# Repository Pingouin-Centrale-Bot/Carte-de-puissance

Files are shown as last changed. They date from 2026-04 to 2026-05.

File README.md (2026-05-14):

# Carte de puissance pour le robot

## Cahier des charges
### Général
 - Connecter une batterie jusqu'à 6s avec un connecteur XT60
 - Génerer une tension 5v
 - Avoir un connecteur pour brancher un convertisseur de tension externe (qu'on appelera V')
 - Alimenter 3 autres cartes, en 3 tensions différentes (Vbatt, 5v, et V')
 - Avoir une sortie dédié à l'alimentation du Pi (sortie en Vbatt)
 - Avoir un bouton (ou entrée bouton) pour l'allumage du système (permet au système de s'éteindre complétement en cas de batterie faible)

### Sécurité du robot
 - Brancher le Bouton d'Arrêt d'Urgence (BAU)
 - Être capable de couper l'alimentation Vbatt et 5v allant vers les cartes annexes
 - Signaler l'état du BAU au Pi (à ROS)

### Protection de la batterie
 - Être capable de couper l'alimentation du Pi
 - Connaitre l'état d'alimentation du Pi (est-il allumé ?)
 - Être capable de couper l'alimentation générale
 - Diode de protection
 - Fusible

### Affichage/feedback
 - Afficher l'état de charge de la batterie (pourcentage sur afficheur 7 segment)
 - Avertissement sonore lorsque la batterie est à plat
 - LED RGB indiquant l'état du système intégré au bouton de mise en marche

### Possibilitées
 - Mesurer le courant sortant de la batterie

## Configuration du pi
Dans `/boot/firmware/config.txt` sur ubuntu :
```
#dtparam=i2c_arm=on
[all]
# So the pi shutdowns when gpio4 is pulled low
dtoverlay=gpio-shutdown,gpio_pin=3,active_low=1,gpio_pull=up
# So the pi 
dtoverlay=gpio-poweroff,gpiopin=4             
```

## Problèmes rencontrés
- [] Il faut mettre une résistance en parallèle des diodes pour le contrôle des mosfets.

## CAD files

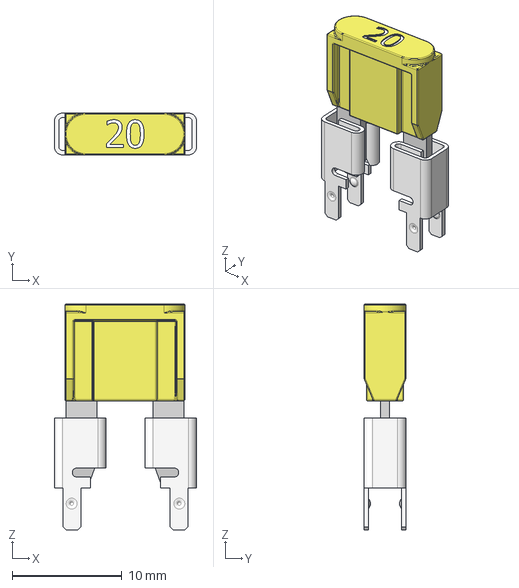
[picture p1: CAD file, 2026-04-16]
Components/3557-2_fuseholder/3557_simple.step
12.9 x 3.80 x 20.6 mm
Fusibile Lama MINI Type 2 x 3
Keystone PCB Blade Fuse Clip_001 x 2

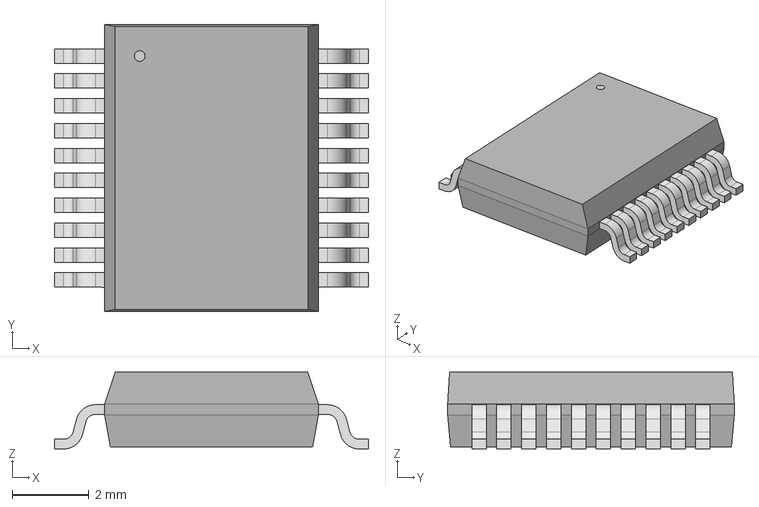
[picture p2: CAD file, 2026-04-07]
Components/ATTiny1626/SSOP20_SS_MCH.step
8.20 x 7.49 x 2.01 mm

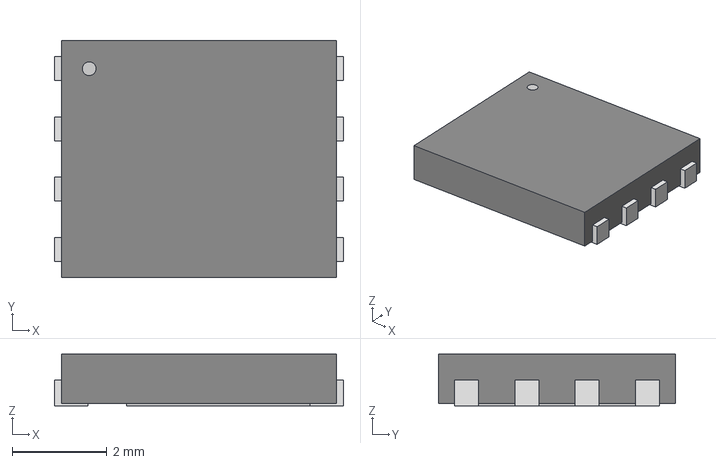
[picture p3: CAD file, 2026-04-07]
Components/GSFP6901/PPAK5X6-8L_GAS.step
6.10 x 5.00 x 1.09 mm

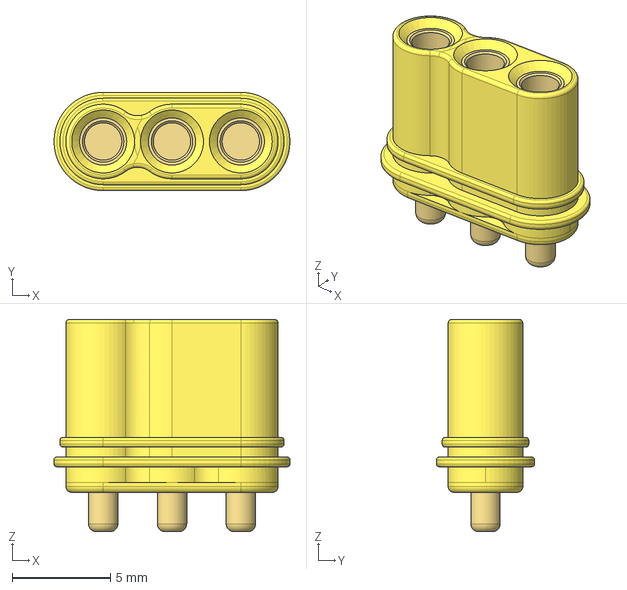
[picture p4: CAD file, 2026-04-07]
Components/MR30PB/Amass_MR30PB-FB.step
12.0 x 5.00 x 10.8 mm

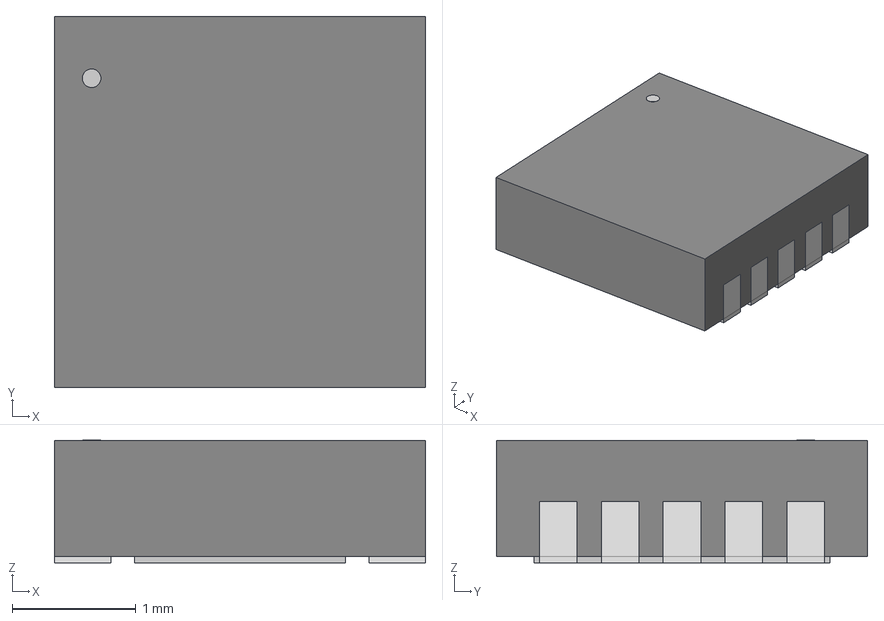
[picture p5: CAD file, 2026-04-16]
Components/PAC1811/VDFN10_9QX_MCH.step
3.00 x 3.00 x 0.993 mm

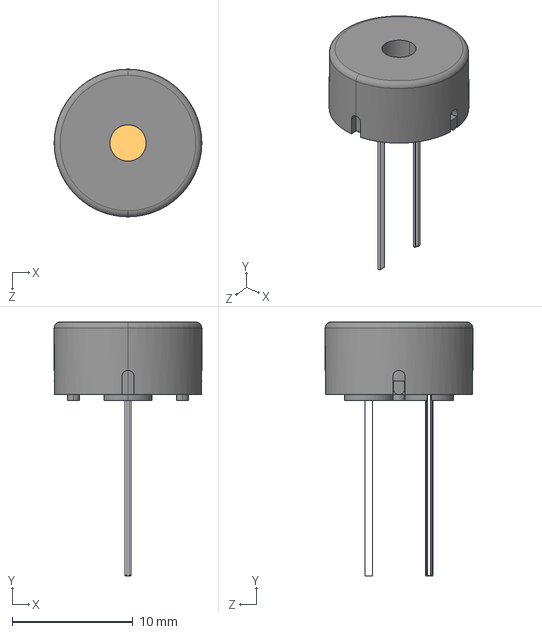
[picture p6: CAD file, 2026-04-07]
Components/PS1240P02BT/PS1240P02BT.step
12.2 x 21.0 x 12.2 mm

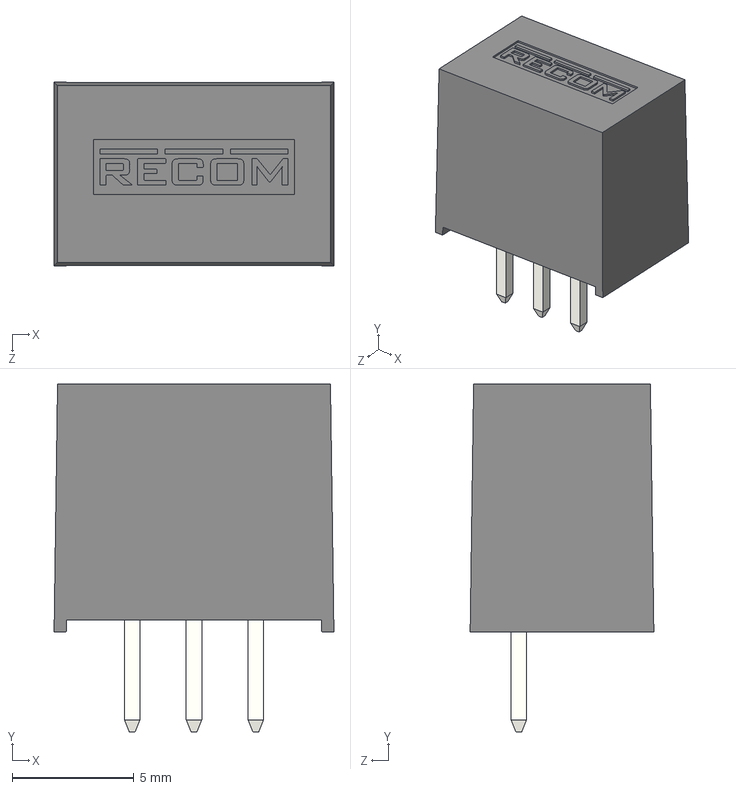
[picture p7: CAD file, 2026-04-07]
Components/R-78K-0.5/R-78K3.3-0.5.step
11.5 x 14.3 x 7.55 mm

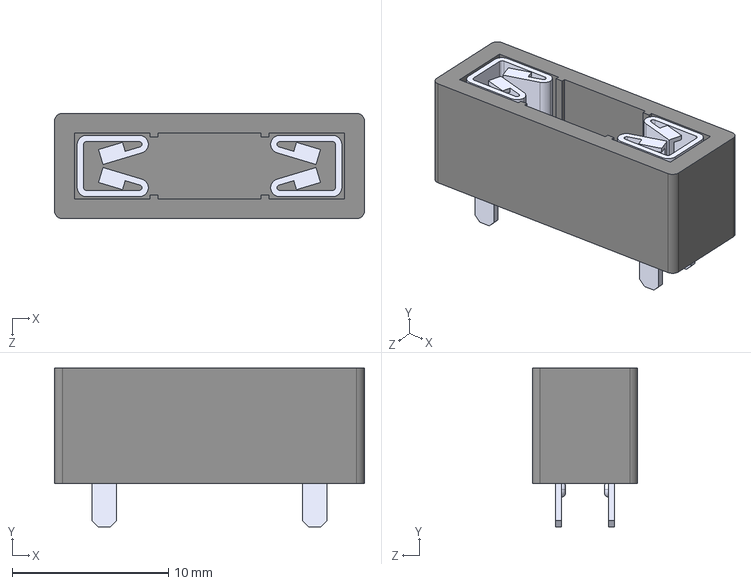
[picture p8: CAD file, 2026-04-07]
Components/3557-2_fuseholder/3557-2.step
19.8 x 10.2 x 6.73 mm

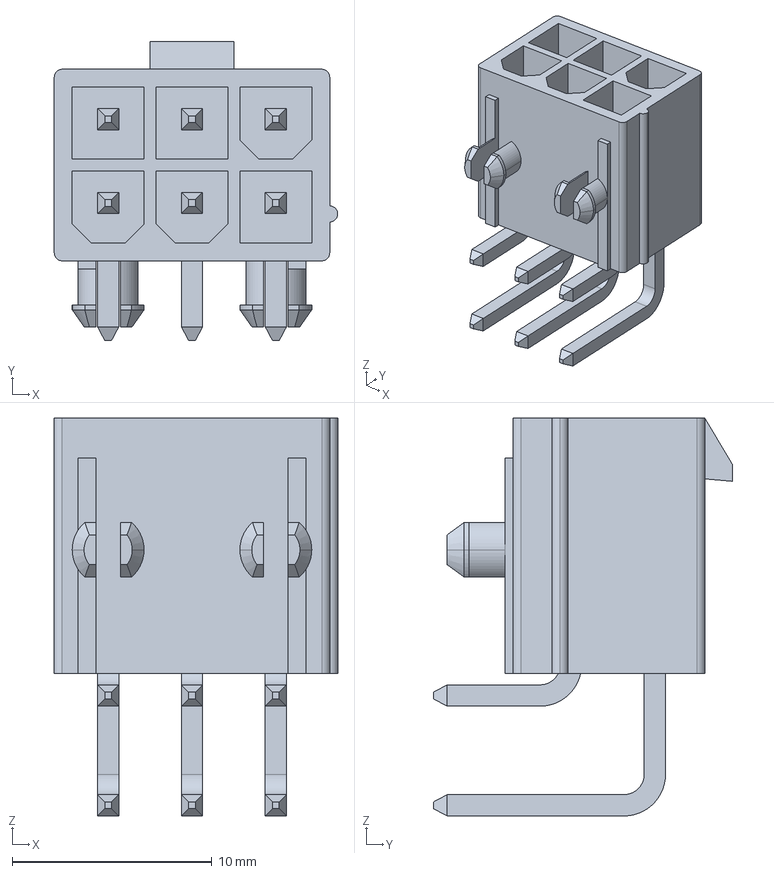
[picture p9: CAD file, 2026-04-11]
Components/Molex/0026013143.stp
14.2 x 15.0 x 19.9 mm

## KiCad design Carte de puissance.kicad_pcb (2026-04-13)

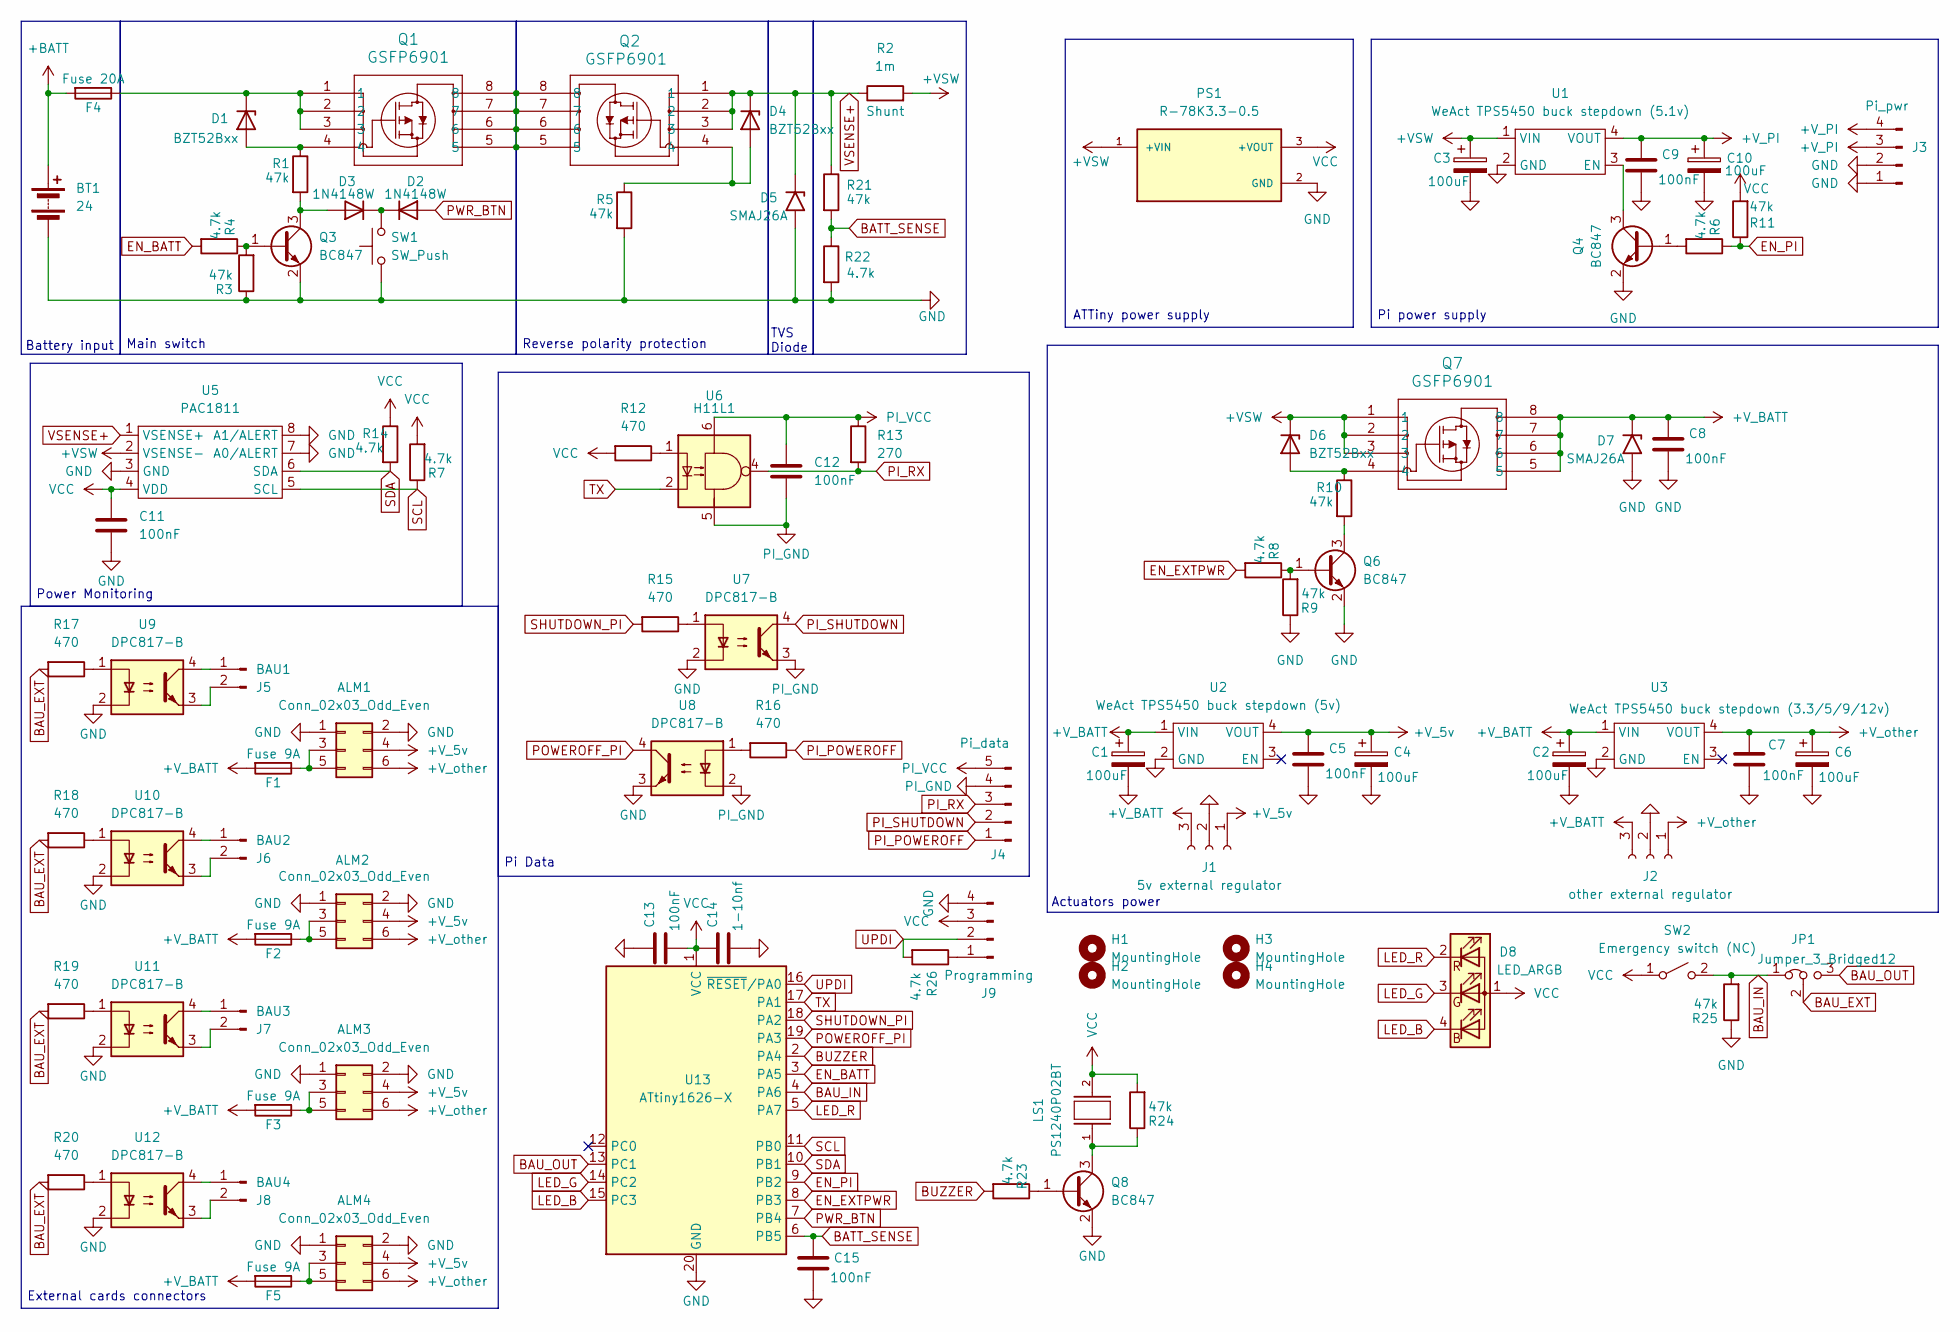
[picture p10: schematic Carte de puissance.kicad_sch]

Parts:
ALM1, ALM2, ALM3, ALM4: Conn_02x03_Odd_Even; Molex_Mini-Fit_Jr_5569-06A2_2x03_P4.20mm_Horizontal
BT1: 24; AMASS_XT60-M_1x02_P7.20mm_Vertical
C1, C2, C3, C4, C6, C10: 100uF; CP_Radial_D6.3mm_P2.50mm
C5, C7, C8, C9, C11, C12, C13, C15: 100nF; C_0805_2012Metric
C14: 1-10nf; C_0805_2012Metric
D1, D4, D6: BZT52Bxx; D_SOD-123F
D2, D3: 1N4148W; D_SOD-123
D5, D7: SMAJ26A; D_SMA
D8: LED_ARGB; JST_XH_B4B-XH-A_1x04_P2.50mm_Vertical
F1, F2, F3, F5: Fuse 9A; FUSE_3557_simple
F4: Fuse 20A; FUSE_3557_simple
H1, H2, H3, H4: MountingHole; MountingHole_3.2mm_M3
J1: 5v external regulator; MR30PB
J2: other external regulator; MR30PB
J3: Pi_pwr; JST_XH_B4B-XH-A_1x04_P2.50mm_Vertical
J4: Pi_data; JST_XH_B5B-XH-A_1x05_P2.50mm_Vertical
J5: BAU1; JST_XH_B2B-XH-A_1x02_P2.50mm_Vertical
J6: BAU2; JST_XH_B2B-XH-A_1x02_P2.50mm_Vertical
J7: BAU3; JST_XH_B2B-XH-A_1x02_P2.50mm_Vertical
J8: BAU4; JST_XH_B2B-XH-A_1x02_P2.50mm_Vertical
J9: Programming; PinHeader_1x04_P2.54mm_Vertical
JP1: Jumper_3_Bridged12; PinHeader_1x03_P2.54mm_Vertical
LS1: PS1240P02BT; XDCR_PS1240P02BT
PS1: R-78K3.3-0.5; CONV_R-78K3.3-0.5; PARTREV 0/2023
Q1, Q2, Q7: GSFP6901; PPAK5X6-8L_GAS
Q3, Q4, Q6, Q8: BC847; SOT-23
R1, R3, R5, R9, R10, R11, R21, R24, R25: 47k; R_0805_2012Metric
R2: 1m; R_2512_6332Metric
R4, R6, R7, R8, R14, R22, R23, R26: 4.7k; R_0805_2012Metric
R12, R15, R16, R17, R18, R19, R20: 470; R_0805_2012Metric
R13: 270; R_0805_2012Metric
SW1: SW_Push; JST_XH_B2B-XH-A_1x02_P2.50mm_Vertical
SW2: Emergency switch (NC); JST_XH_B2B-XH-A_1x02_P2.50mm_Vertical
U1: WeAct TPS5450 buck stepdown (5.1v); WeAct TPS5450 Buck Stepdown
U2: WeAct TPS5450 buck stepdown (5v); WeAct TPS5450 Buck Stepdown
U3: WeAct TPS5450 buck stepdown (3.3/5/9/12v); WeAct TPS5450 Buck Stepdown
U5: PAC1811
U6: H11L1; SMDIP-6_W9.53mm
U7, U8, U9, U10, U11, U12: DPC817-B; SMDIP-4_W11.48mm
U13: ATtiny1626-X; SSOP-20_5.3x7.2mm_P0.65mm

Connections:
+BATT: BT1.1 (+), F4.2
+VSW: C3.1, D6.1 (K), PS1.1 (+VIN), Q7.1, Q7.2, Q7.3, R2.2, U1.1 (VIN), U5.2 (VSENSE-)
+V_5v: ALM1.4, ALM2.4, ALM3.4, ALM4.4, C4.1, C5.1, J1.1, U2.4 (VOUT)
+V_BATT: C1.1, C2.1, C8.1, D7.1 (A1), F1.2, F2.2, F3.2, F5.2, J1.3, J2.3, Q7.5, Q7.6, Q7.7, Q7.8, U2.1 (VIN), U3.1 (VIN)
+V_PI: C9.1, C10.1, J3.3, J3.4, U1.4 (VOUT)
+V_other: ALM1.6, ALM2.6, ALM3.6, ALM4.6, C6.1, C7.1, J2.1, U3.4 (VOUT)
BATT_SENSE: C15.1, R21.2, R22.1, U13.6 (PB5)
BAU_EXT: JP1.2 (C), R17.2, R18.2, R19.2, R20.2
BAU_IN: JP1.1 (A), R25.2, SW2.2 (B), U13.4 (PA6)
BAU_OUT: JP1.3 (B), U13.13 (PC1)
BUZZER: R23.2, U13.2 (PA4)
EN_BATT: R4.2, U13.3 (PA5)
EN_EXTPWR: R8.2, U13.8 (PB3)
EN_PI: R6.1, R11.1, U13.9 (PB2)
GND: ALM1.1, ALM1.2, ALM2.1, ALM2.2, ALM3.1, ALM3.2, ALM4.1, ALM4.2, BT1.2 (-), C1.2, C2.2, C3.2, C4.2, C5.2, C6.2, C7.2, C8.2, C9.2, C10.2, C11.2, C13.1, C14.2, C15.2, D5.2 (A2), D7.2 (A2), J1.2, J2.2, J3.1, J3.2, J9.4, PS1.2 (GND), Q3.2 (E), Q4.2 (E), Q6.2 (E), Q8.2 (E), R3.1, R5.2, R9.1, R22.2, R25.1, SW1.1, U1.2 (GND), U2.2 (GND), U3.2 (GND), U5.3 (GND), U5.7 (A0/ALERT), U5.8 (A1/ALERT), U7.2, U8.3, U9.2, U10.2, U11.2, U12.2, U13.20 (GND)
LED_B: D8.4 (BK), U13.15 (PC3)
LED_G: D8.3 (GK), U13.14 (PC2)
LED_R: D8.2 (RK), U13.5 (PA7)
unnamed: ALM1.3, ALM1.5, F1.1
unnamed: ALM2.3, ALM2.5, F2.1
unnamed: ALM3.3, ALM3.5, F3.1
unnamed: ALM4.3, ALM4.5, F5.1
unnamed: D1.2 (A), Q1.4, R1.1
unnamed: D1.1 (K), F4.1, Q1.1, Q1.2, Q1.3
unnamed: D2.1 (K), D3.1 (K), SW1.2
unnamed: D3.2 (A), Q3.3 (C), R1.2
unnamed: D4.2 (A), Q2.4, R5.1
unnamed: D6.2 (A), Q7.4, R10.1
unnamed: J5.1, U9.4
unnamed: J5.2, U9.3
unnamed: J6.1, U10.4
unnamed: J6.2, U10.3
unnamed: J7.1, U11.4
unnamed: J7.2, U11.3
unnamed: J8.1, U12.4
unnamed: J8.2, U12.3
unnamed: J9.1, R26.1
unnamed: Q1.5, Q1.6, Q1.7, Q1.8, Q2.5, Q2.6, Q2.7, Q2.8
unnamed: Q3.1 (B), R3.2, R4.1
unnamed: Q4.1 (B), R6.2
unnamed: Q4.3 (C), U1.3 (EN)
unnamed: Q6.1 (B), R8.1, R9.2
unnamed: Q6.3 (C), R10.2
unnamed: Q8.1 (B), R23.1
unnamed: LS1.1, Q8.3 (C), R24.1
unnamed: R12.1, U6.1
unnamed: R15.1, U7.1
unnamed: R16.2, U8.1
unnamed: R17.1, U9.1
unnamed: R18.1, U10.1
unnamed: R19.1, U11.1
unnamed: R20.1, U12.1
PI_GND: C12.2, J4.4, U6.5, U7.3, U8.2
PI_POWEROFF: J4.1, R16.1
PI_RX: J4.3, R13.2, U6.4
PI_SHUTDOWN: J4.2, U7.4
PI_VCC: C12.1, J4.5, R13.1, U6.6
POWEROFF_PI: U8.4, U13.19 (PA3)
PWR_BTN: D2.2 (A), U13.7 (PB4)
SCL: R7.1, U5.5 (SCL), U13.11 (PB0)
SDA: R14.2, U5.6 (SDA), U13.10 (PB1)
SHUTDOWN_PI: R15.2, U13.18 (PA2)
TX: U6.2, U13.17 (PA1)
UPDI: J9.2, R26.2, U13.16 (~RESET/PA0)
VCC: C11.1, C13.2, C14.1, D8.1 (A), J9.3, LS1.2, PS1.3 (+VOUT), R7.2, R11.2, R12.2, R14.1, R24.2, SW2.1 (A), U5.4 (VDD), U13.1 (VCC)
VSENSE+: D4.1 (K), D5.1 (A1), Q2.1, Q2.2, Q2.3, R2.1, R21.1, U5.1 (VSENSE+)

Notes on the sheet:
Actuators power
ATTiny power supply
Pi Data
Pi power supply
External cards connectors
Power Monitoring
Main switch
TVS Diode
Battery input
Reverse polarity protection

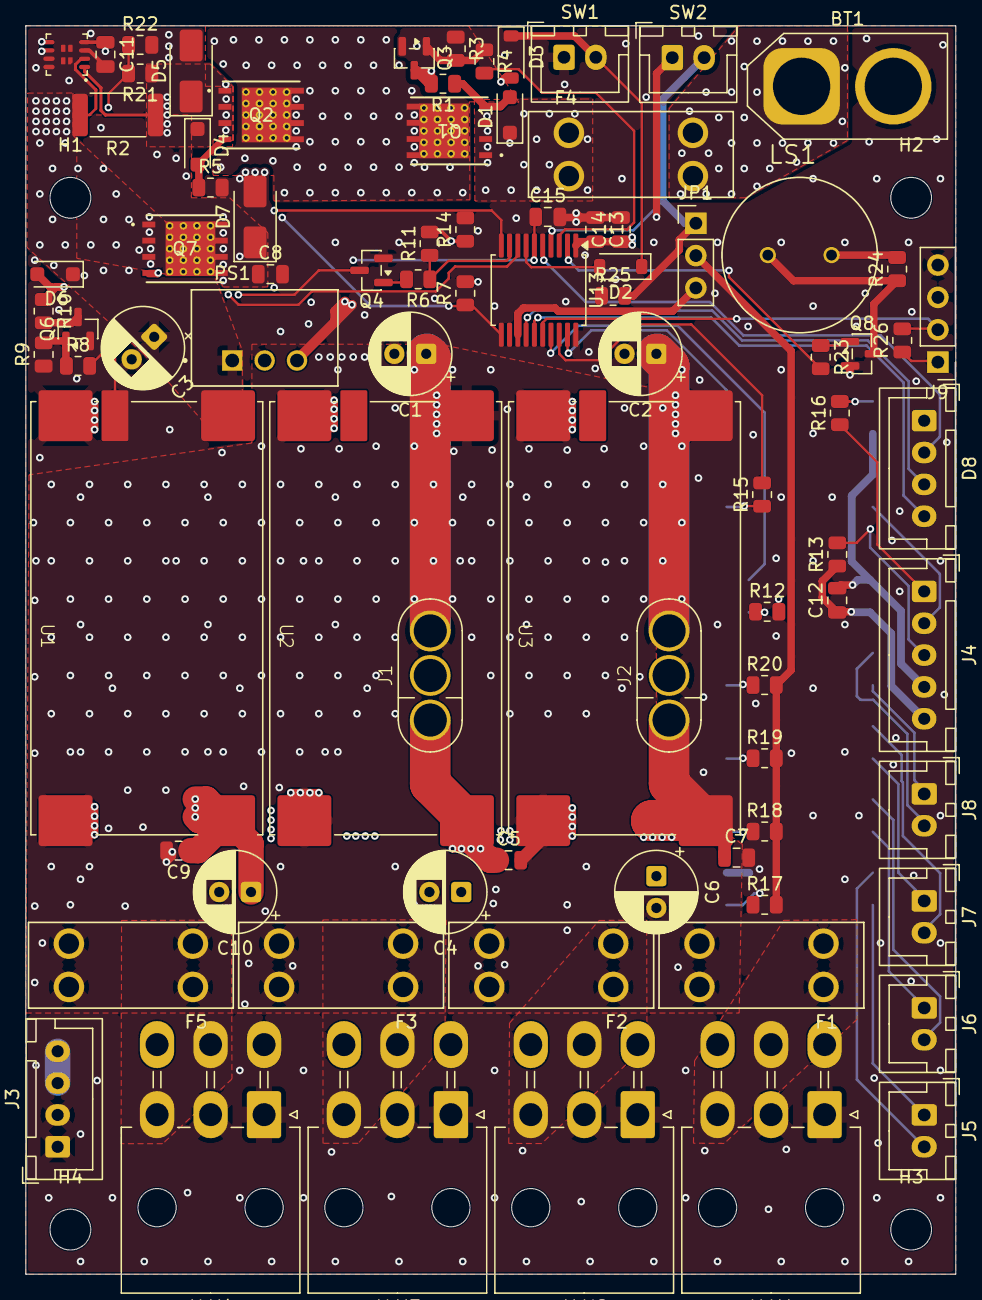
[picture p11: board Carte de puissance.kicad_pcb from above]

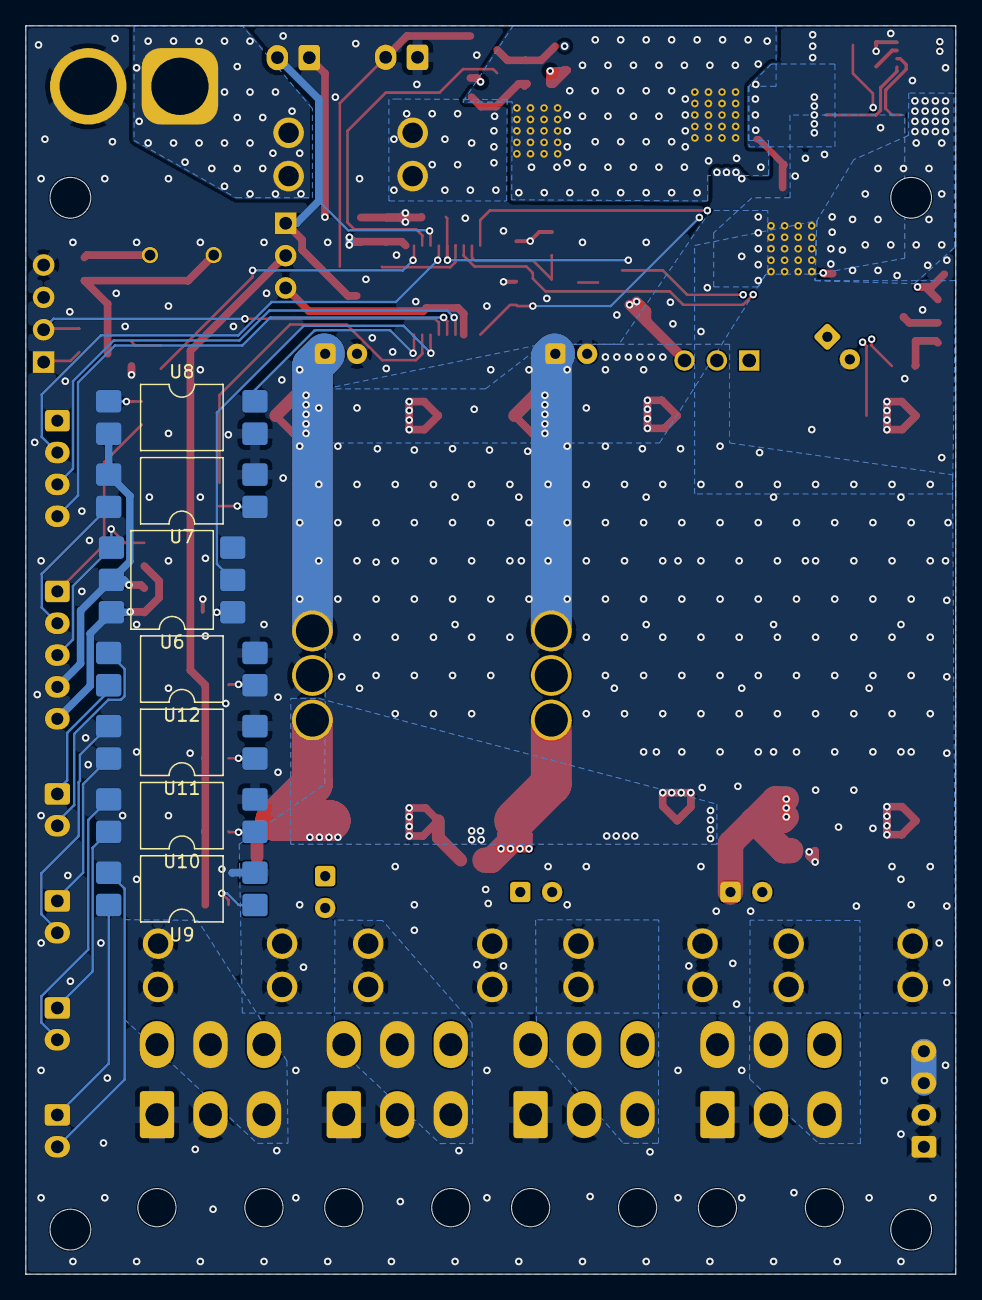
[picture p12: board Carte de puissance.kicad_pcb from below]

Board: 4 copper layers, 73.0 x 98.0 mm, 96 parts (7 on the bottom side), 66 nets.

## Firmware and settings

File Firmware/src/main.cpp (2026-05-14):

#include <Arduino.h>
#include "config.hpp"

enum Msg
{
  CRITICAL_LOW_BATT_MSG,
  CRITICAL_HIGH_BATT_MSG,
  PI_NOT_OFF_MSG,
  NORMAL_OFF_MSG,
  POWERING_UP_MSG
};

enum BattState
{
  START_BATT_STATE,
  HIGH_BATT_STATE,
  NORMAL_BATT_STATE,
  MEDIUM_BATT_STATE,
  LOW_BATT_STATE,
  VERY_LOW_BATT_STATE,
  POWERING_OFF_ENTER,
  POWERING_OFF_WAITING_FOR_PI
};
volatile BattState batt_state = START_BATT_STATE;
volatile unsigned long powering_off_enter_time = 0;

enum BAUState
{
  IDLE_BAU,
  PRESSED_TIMEOUT_BEFORE_POWERCUT,
  POWERCUT
};

volatile BAUState BAU_state = IDLE_BAU;
volatile bool BAU_state_changed;

void handle_bau()
{
  if (BAU_state == IDLE_BAU && !(batt_state >= POWERING_OFF_ENTER))
  {
    BAU_state = PRESSED_TIMEOUT_BEFORE_POWERCUT;
    digitalWriteFast(BAU_OUT, LOW);
    BAU_state_changed = true;
    tone(BUZZER, LOW_NOTE, 2000);
  }
}

void handle_power_btn()
{
  if (millis() >= 1500 && batt_state < POWERING_OFF_ENTER) // To prevent issues if pressed too soon with debouncing
  {
    powering_off_enter_time = millis();
  }
}

uint16_t readVoltageMV()
{
  return analogRead(BATT_SENSE) * (2.5 / 4095) * ((47 + 4.7) / 4.7) * BATT_CORRECT * 1000;
}

inline void setRGB(Color c)
{
  digitalWriteFast(LED_R, ((c >> 2) & 0x01) == 0);
  digitalWriteFast(LED_G, ((c >> 1) & 0x01) == 0);
  digitalWriteFast(LED_B, ((c >> 0) & 0x01) == 0);
}

inline void playCode(Color c, unsigned int tone_f, bool end_delay = true)
{
  tone(BUZZER, tone_f);
  setRGB(c);
  delay(100);
  if (!end_delay)
  {
    delay(100);
  }
  noTone(BUZZER);
  setRGB(Black);
  if (end_delay)
  {
    delay(100);
  }
}

void playMsg(Msg error)
{
  switch (error)
  {
  case CRITICAL_HIGH_BATT_MSG:
    playCode(HIGH_COLOR, HIGH_NOTE);
    playCode(HIGH_COLOR, HIGH_NOTE);
    playCode(HIGH_COLOR, HIGH_NOTE);
    Serial1.println("Critical high batt");
    break;
  case CRITICAL_LOW_BATT_MSG:
    playCode(LOW_COLOR, LOW_NOTE);
    playCode(LOW_COLOR, LOW_NOTE);
    playCode(LOW_COLOR, LOW_NOTE);
    Serial1.println("Critical low batt");
    break;
  case PI_NOT_OFF_MSG:
    playCode(HIGH_COLOR, HIGH_NOTE);
    playCode(MEDIUM_COLOR, MEDIUM_NOTE);
    playCode(HIGH_COLOR, HIGH_NOTE);
    playCode(MEDIUM_COLOR, MEDIUM_NOTE);
    // Followed by normal power off.
  case NORMAL_OFF_MSG:
    playCode(HIGH_COLOR, HIGH_NOTE, false);
    playCode(MEDIUM_COLOR, MEDIUM_NOTE, false);
    playCode(LOW_COLOR, LOW_NOTE, false);
    break;
  case POWERING_UP_MSG:
    playCode(LOW_COLOR, LOW_NOTE, false);
    playCode(MEDIUM_COLOR, MEDIUM_NOTE, false);
    playCode(HIGH_COLOR, HIGH_NOTE, false);
    break;
  }
}

void unplugBattery()
{
  digitalWriteFast(EN_BATT, LOW);
  delay(2000);
  tone(BUZZER, 2489); // Should be off by now. The tone indicates user should disconnect power ASAP.
  while (true)
    ;
}

bool updateBattState() // Will unplug if battery critical
{
  uint16_t batt_voltage = readVoltageMV();
  Serial1.printf("Voltage: %d;\n", batt_voltage);
  if (batt_voltage >= CRITICAL_HIGH_BATT)
  {
    playMsg(CRITICAL_HIGH_BATT_MSG);
    unplugBattery(); // Never returns
  }
  else if (batt_voltage <= CRITICAL_LOW_BATT || (batt_state == START_BATT_STATE && batt_voltage <= VERY_LOW_BATT))
  {
    playMsg(CRITICAL_LOW_BATT_MSG);
    unplugBattery(); // Never returns
  }

  if (batt_voltage <= VERY_LOW_BATT && batt_state < POWERING_OFF_ENTER)
  {
    batt_state = POWERING_OFF_ENTER;
    return true;
  }
  else if (batt_voltage <= LOW_BATT && batt_state < VERY_LOW_BATT_STATE)
  {
    batt_state = VERY_LOW_BATT_STATE;
    return true;
  }
  else if (batt_voltage <= MEDIUM_BATT && batt_state < LOW_BATT_STATE)
  {
    batt_state = LOW_BATT_STATE;
    return true;
  }
  else if (batt_voltage <= NORMAL_BATT && batt_state < MEDIUM_BATT_STATE)
  {
    batt_state = MEDIUM_BATT_STATE;
    return true;
  }
  else if (batt_voltage <= HIGH_BATT && batt_state < NORMAL_BATT_STATE)
  {
    batt_state = NORMAL_BATT_STATE;
    return true;
  }
  else if (batt_state < HIGH_BATT_STATE)
  {
    batt_state = HIGH_BATT_STATE;
    return true;
  }
  return false;
}

void setup()
{
  while (millis() < 1000); // To prevent accidental power on

  Serial1.begin(115200);

  // Power control
  pinModeFast(EN_BATT, OUTPUT);
  digitalWriteFast(EN_BATT, HIGH); // Latch power
  pinModeFast(EN_EXTPWR, OUTPUT);
  digitalWriteFast(EN_EXTPWR, LOW);
  pinModeFast(EN_PI, OUTPUT);
  digitalWriteFast(EN_PI, LOW);

  // Batt sense
  pinModeFast(BATT_SENSE, INPUT);
  analogReference(INTERNAL2V5);
  analogReadResolution(12);

  // RGB LED
  pinModeFast(LED_R, OUTPUT);
  pinModeFast(LED_G, OUTPUT);
  pinModeFast(LED_B, OUTPUT);
  digitalWriteFast(LED_R, HIGH);
  digitalWriteFast(LED_G, HIGH);
  digitalWriteFast(LED_B, LOW);

  // Buzzer
  pinModeFast(BUZZER, OUTPUT);
  digitalWriteFast(BUZZER, LOW);

  // Check batt voltage
  updateBattState(); // Will prevent further power on if the batt is low.

  // BAU (Emergency Button)
  pinModeFast(BAU_IN, INPUT);
  pinModeFast(BAU_OUT, OUTPUT);
  attachInterrupt(BAU_IN, handle_bau, FALLING);
  if (digitalReadFast(BAU_IN))
  {
    BAU_state = IDLE_BAU;
    digitalWriteFast(EN_EXTPWR, HIGH);
    digitalWriteFast(BAU_OUT, HIGH);
  }
  else
  {
    BAU_state = POWERCUT;
    digitalWriteFast(EN_EXTPWR, LOW);
    digitalWriteFast(BAU_OUT, LOW);
  }

  // Pi Communications
  pinModeFast(SHUTDOWN_PI, OUTPUT);
  digitalWriteFast(SHUTDOWN_PI, LOW);
  pinModeFast(POWEROFF_PI, INPUT_PULLUP);

  // Power btn
  pinModeFast(PWR_BTN, INPUT_PULLUP);
  attachInterrupt(PWR_BTN, handle_power_btn, FALLING);

  // TODO : PAC1811

  playMsg(POWERING_UP_MSG);
}

void loop()
{
  unsigned long current = millis();
  static unsigned long last_batt_state_update = current;
  static unsigned long last_pac1811_measure = current;
  static unsigned long last_led_change = current;
  static unsigned long pi_poweroff_time;
  static unsigned long BAU_pressed_time;
  static bool led_state = true;

  static bool state_changed = true;

  if (powering_off_enter_time > 0)
  {
    if (!digitalReadFast(PWR_BTN))
    {
      if (current - powering_off_enter_time > 1000)
      {
        batt_state = POWERING_OFF_ENTER;
        state_changed = true;
      }
    }
    else
    {
      powering_off_enter_time = 0;
    }
  }

  // LED and main power control
  switch (batt_state)
  {
  case HIGH_BATT_STATE:
    if (state_changed)
    {
      setRGB(Green);
    }
    break;
  case NORMAL_BATT_STATE:
    if (state_changed)
    {
      setRGB(Yellow);
    }
    break;
  case MEDIUM_BATT_STATE:
    if (state_changed)
    {
      setRGB(Red);
    }
    break;
  case LOW_BATT_STATE:
    if (current - last_led_change > 1000)
    {
      setRGB(led_state ? Red : Black);
      if (led_state)
      {
        tone(BUZZER, DEFAULT_NOTE, 150);
      }
      led_state = !led_state;
      last_led_change = current;
    }
    break;
  case VERY_LOW_BATT_STATE:
    if (current - last_led_change > 250)
    {
      setRGB(led_state ? Red : Black);
      if (led_state)
      {
        tone(BUZZER, DEFAULT_NOTE, 200);
      }
      led_state = !led_state;
      last_led_change = current;
    }
    break;
  case POWERING_OFF_ENTER:
    digitalWriteFast(SHUTDOWN_PI, HIGH); // Ask pi to poweroff
    BAU_state = PRESSED_TIMEOUT_BEFORE_POWERCUT;
    BAU_state_changed = true;
    batt_state = POWERING_OFF_WAITING_FOR_PI;
    pi_poweroff_time = current;
    tone(BUZZER, MEDIUM_NOTE, 200);
    // no break on purpose, to continue for next state when using NINJA
  case POWERING_OFF_WAITING_FOR_PI:
    if ((!digitalReadFast(POWEROFF_PI)) or NINJA)
    {
      playMsg(NORMAL_OFF_MSG);
      unplugBattery(); // Does not return
    }
    else if (current - pi_poweroff_time > 60 * 1000) // Timeout, if the pi does not poweroff...
    {
      playMsg(PI_NOT_OFF_MSG);
      unplugBattery(); // Does not return
    }
    if (current - last_led_change > 500)
    {
      setRGB(led_state ? Black : Blue);
      digitalWriteFast(SHUTDOWN_PI, led_state ? LOW : HIGH); // to ask repeatidly the pi to power off
      led_state = !led_state;
      last_led_change = current;
    }
    break;
  default:
    break;
  }

  switch (BAU_state)
  {
  case IDLE_BAU:
    if (BAU_state_changed && !(batt_state >= POWERING_OFF_ENTER))
    {
      tone(BUZZER, HIGH_NOTE, 500);
      digitalWriteFast(BAU_OUT, HIGH);
      digitalWriteFast(EN_EXTPWR, HIGH);
      Serial1.print("BAU: Depressed;\n");
      BAU_state_changed = false;
    }
    break;

  case PRESSED_TIMEOUT_BEFORE_POWERCUT:
    if (BAU_state_changed)
    {
      BAU_pressed_time = current;
      BAU_state_changed = false;
    }
    if (current - BAU_pressed_time > BAU_delay_before_powercut)
    {
      digitalWriteFast(EN_EXTPWR, LOW);
      BAU_state = POWERCUT;
      BAU_state_changed = true;
    }
    break;

  case POWERCUT:
  {
    static bool first_time = true;
    if (digitalReadFast(BAU_IN))
    {
      // Debouncing
      if (first_time)
      {
        first_time = false;
        BAU_pressed_time = current;
      }
      else if (current - BAU_pressed_time > 100)
      {
        BAU_state = IDLE_BAU;
        BAU_state_changed = true;
        break;
      }
    }
    else
    {
      first_time = true;
    }
    BAU_state_changed = false;
    break;
  }

  default:
    break;
  }

  // PAC1811
  if (current - last_pac1811_measure > pac1811_measure_period)
  {
    if (BAU_state == IDLE_BAU)
    {
      Serial1.println("BAU: Depressed;");
    }
    else
    {
      Serial1.println("BAU: Pressed;");
    }
    last_pac1811_measure = current;
  }

  if (current - last_batt_state_update > batt_state_update_period)
  {
    state_changed = updateBattState();
    last_batt_state_update = current;
  }
  else
  {
    state_changed = false;
  }
}

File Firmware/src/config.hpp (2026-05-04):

#include <Arduino.h>

static const pin_size_t TX = PIN_PA1;
static const pin_size_t SHUTDOWN_PI = PIN_PA2; // To shutdown the Pi
static const pin_size_t POWEROFF_PI = PIN_PA3; // To tell if the Pi is shutdown
static const pin_size_t BUZZER = PIN_PA4;
static const pin_size_t EN_BATT = PIN_PA5;
static const pin_size_t BAU_IN = PIN_PA6;
static const pin_size_t LED_R = PIN_PA7;

// static const pin_size_t SCL = PIN_PB0; already exists
// static const pin_size_t SDA = PIN_PB1; already exists
static const pin_size_t EN_PI = PIN_PB2;
static const pin_size_t EN_EXTPWR = PIN_PB3;
static const pin_size_t PWR_BTN = PIN_PB4;
static const pin_size_t BATT_SENSE = PIN_PB5;

static const pin_size_t BAU_OUT = PIN_PC1;
static const pin_size_t LED_G = PIN_PC2;
static const pin_size_t LED_B = PIN_PC3;

static const float BATT_CORRECT = 24.18 / 24.00;
#ifdef ROBOT // 6s LiPo
static const int CELL_COUNT = 6;
static const uint16_t CRITICAL_HIGH_BATT = 1000 * 4.22 * CELL_COUNT; // Refuse to power on or power off if higher.
static const uint16_t HIGH_BATT = 1000 * 3.9 * CELL_COUNT;           // about 80% charge (green)
static const uint16_t NORMAL_BATT = 1000 * 3.75 * CELL_COUNT;        // about 40% charge (orange)
static const uint16_t MEDIUM_BATT = 1000 * 3.6 * CELL_COUNT;         // about 20% charge (red)
static const uint16_t LOW_BATT = 1000 * 3.5 * CELL_COUNT;            // about 10% charge (slow flashing red)
static const uint16_t VERY_LOW_BATT = 1000 * 3.4 * CELL_COUNT;       // about 5% charge (fast flashing red, force soft power off if lower)
static const uint16_t CRITICAL_LOW_BATT = 1000 * 3.1 * CELL_COUNT;   // If lower, refuse to power on or hard power off.
#endif
#ifdef NINJA // 4s LiFePo4
static const int CELL_COUNT = 4;
static const uint16_t CRITICAL_HIGH_BATT = 1000 * 3.65 * CELL_COUNT; // Refuse to power on or power off if higher.
static const uint16_t HIGH_BATT = 1000 * 3.32 * CELL_COUNT;          // about 80% charge (green)
static const uint16_t NORMAL_BATT = 1000 * 3.25 * CELL_COUNT;        // about 40% charge (orange)
static const uint16_t MEDIUM_BATT = 1000 * 3.2 * CELL_COUNT;         // about 20% charge (red)
static const uint16_t LOW_BATT = 1000 * 3.0 * CELL_COUNT;            // about 10% charge (slow flashing red)
static const uint16_t VERY_LOW_BATT = 1000 * 2.8 * CELL_COUNT;       // about 5% charge (fast flashing red, force soft power off if lower)
static const uint16_t CRITICAL_LOW_BATT = 1000 * 2.55 * CELL_COUNT;  // If lower, refuse to power on or hard power off.
#endif
#ifndef NINJA
#define NINJA false
#endif

enum Color : uint8_t
{
  Black = 0b000, // All off
  Red = 0b100,
  Green = 0b010,
  Blue = 0b001,
  Yellow = 0b110,  // Red + Green
  Magenta = 0b101, // Red + Blue
  Cyan = 0b011,    // Green + Blue
  White = 0b111    // All on
};

static const unsigned int LOW_NOTE = 1568;
static const unsigned int MEDIUM_NOTE = 1976;
static const unsigned int HIGH_NOTE = 2349;
static const unsigned int DEFAULT_NOTE = 2349;

static const Color LOW_COLOR = Cyan;
static const Color MEDIUM_COLOR = Magenta;
static const Color HIGH_COLOR = Yellow;

static const unsigned long batt_state_update_period = 200;  // ms
static const unsigned long pac1811_measure_period = 250;    // ms
static const unsigned long BAU_delay_before_powercut = 250; // ms

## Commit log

2026-04-07 Schematic fait
    [Carte de puissance.kicad_pcb, Carte de puissance.kicad_sch, PPAK5X6-8L_GAS.step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]
2026-04-07 Mise à jour de certains footprints
    [Carte de puissance.kicad_sch]
2026-04-07 Placement des composants
    [Carte de puissance.kicad_pcb, Carte de puissance.kicad_sch]
2026-04-07 Placement pour avoir une carte au format du module
    [Carte de puissance.kicad_pcb, Carte de puissance.kicad_sch]
2026-04-07 début de routage
    [Carte de puissance.kicad_pcb, Carte de puissance.kicad_sch]
2026-04-07 Changement des empreintes de fusible
    [3557-2.step, 3557_simple.step, Carte de puissance.kicad_pcb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]
2026-04-07 Ajout de l'empreinte des MR30PB
    [Amass_MR30PB-FB.step, Carte de puissance.kicad_pcb, Carte de puissance.kicad_sch]
2026-04-11 Routage V2 partiel
    [0026013143.stp, Carte de puissance.kicad_pcb, Carte de puissance.kicad_sch]
2026-04-12 Routage V2 signaux fini Il reste encore la puissance à finir
    [Carte de puissance.kicad_pcb, Carte de puissance.kicad_sch]
2026-04-12 Routage fini reste à corriger les erreurs DRC, et à faire les graphiques
    [Carte de puissance.kicad_pcb]
2026-04-13 Routing and debugging done, missing silkscreen
    [Carte de puissance.kicad_pcb]
2026-04-13 Carte principale fini
    [Carte de puissance.kicad_sch]
2026-04-16 Ajout des modèles 3D manquants
    [3557_simple.step, VDFN10_9QX_MCH.step]
2026-05-04 Code de firmware
2026-05-06 Correction of BAU startup routine
    [main.cpp]
2026-05-14 Correction des dernières erreurs
    [main.cpp]
